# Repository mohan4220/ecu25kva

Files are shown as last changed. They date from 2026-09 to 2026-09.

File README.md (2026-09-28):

# Genset ECU

Replacement engine control unit for a 25 kVA Kirloskar diesel genset —
engine **3GK550ETA 4SR1**, application code `GK3.8703`, 26.5 kW at 1500 rpm,
12 V system. Panel controller is a **Deep Sea Electronics DSE4522 MKII AMF**.

## Start here

**[`docs/pdf/ECU-Bible.pdf`](docs/pdf/ECU-Bible.pdf)** — everything, in reading
order, in one 328-page file. Cover, handoff, field handbook, sensor reference,
circuit reference, the specification, the decisions log, all twelve research
memos, the plan. Bookmarked, so the PDF reader's outline pane is the table of
contents.

Resuming work, or moving to another machine?
**[`docs/HANDOFF.md`](docs/HANDOFF.md)** — setup, what is verified, what is
open, and the traps that already cost a session each.
**[`docs/decisions-log.md`](docs/decisions-log.md)** — every design fork put to
the owner, with the options and the reasoning.

Prefer the browser? Three of those are live HTML:
[the handbook](docs/handbook/index.html),
[the circuit reference](docs/handbook/circuits.html) and
[the sensor reference](docs/handbook/sensors.html).

## What's in here

| Path | What it is |
|---|---|
| `docs/pdf/` | Every document as PDF — one file each, plus the combined bible |
| `docs/handbook/index.html` | The handbook: machine, 94-pin interface, the circuits in narrative, how a runaway gets stopped |
| `docs/handbook/circuits.html` | Circuit reference — all 17 blocks, each with schematic, reasoning, simulated result and model limits |
| `docs/handbook/sensors.html` | Sensor reference — every sensor, what it measures, how it's read, what the data drives |
| `docs/superpowers/specs/` | The reconciled specification — the binding source of truth |
| `refs/` | The OEM wiring diagram, the DSE4522 configuration, machine photographs, and the extracted pinout |
| `docs/research/` | Twelve research memos: engine ID, GCU, connector, injector, MCU, standards, BOM, inspection brief, sensor front-ends, injector turn-off, supervisor, driver architecture |
| `sim/` | Twenty-four SPICE circuits that run and check themselves |
| `hw/` | The ten schematic-sheet generators, the symbol/footprint generators and the netlist gate |

## Rebuilding the PDFs

```bash
.venv/bin/python docs/build_pdf.py
```

Markdown documents are converted and printed; the handbook pages are printed as
they stand, from a temporary copy with the print rules injected — the source
HTML is never edited, so a PDF cannot drift from the page it came from.

Needs Chrome or Chromium on `PATH` (it is the renderer — the only engine here
that handles the handbook's inline SVG schematics and CSS custom properties),
plus `markdown` and `pypdf`:

```bash
.venv/bin/pip install markdown pypdf
```

Page rules live in [`docs/print.css`](docs/print.css).

## Running the circuit simulations

```bash
.venv/bin/python sim/run_sim.py              # every block
.venv/bin/python sim/run_sim.py injector     # blocks matching "injector"
```

Each check is a claim about the circuit, so a red line means the **design** is
wrong, not the simulator. All seventeen blocks currently pass.

The netlists are plain SPICE — they also open directly in KiCad's built-in
simulator (Tools → Simulator), LTspice, or standalone ngspice. See
[`sim/README.md`](sim/README.md).

If `.venv` is missing, rebuild it:

```bash
python3 -m venv .venv && .venv/bin/pip install PySpice numpy schemdraw markdown pypdf
```

## Where the project stands

Phase 1 is complete: nine research memos, **seventeen verified circuit blocks**
covering the whole power chain, both sensor front-end topologies, the speed
input, the injector boost rail and its reservoir, both actuator drivers and the
CAN termination — and a specification carrying the corrections that simulation
forced, including one front-end that could not have worked as originally
specified.

Simulation has now caught a design error in roughly a third of the blocks
written. The ones worth knowing about: the discrete input was impossible as a
divider rather than merely mis-valued; the battery divider would have destroyed
an ADC pin; the MCU decoupling peaked thirty times over target against the
regulator's own output inductance; and the EMI filter handed back 12 dB at the
exact frequency it most needed to hold.

**Four unknowns closed on 18 September**, from photographs of the machine and one
manufacturer's manual — and three of the four closed *against* an inference this
project had made. The engine is **3GK550ETA 4SR1**, not the model memo 01 derived.
The panel controller is a **DSE4522**, not the KG640C the OEM diagram shows. The
connector is **Bosch `1 928 405 192` / `194`, code C**. And the controller has no
speed pickup, which memo 02 got right about the wrong device.

That cost the project its safety argument. The DSE4522 takes engine speed from
**our ECU over CAN**, so its overspeed trip is not independent of the thing it
protects against. Spec §3 is rewritten and the standalone overspeed trip module
reverts from *recommended* to **mandatory**.

**U12 now stands alone as the load-bearing unknown.** Every protective action the
controller can take ends by de-energising one fuel relay; whether its contacts
remove supply from the ECU and fuel system, or merely signal a hung ECU, decides
whether any independent protection exists.
[Memo 08](docs/research/08-engine-inspection-brief.md) is the printed checklist
for that measurement.

Three things deserve reading before anything gets built. **Memo 06** on the CPCB
IV+ position — and the machine's type approval is now a specific certificate,
`ARAI/MoEF/DGTA/IGES4/KOEL-P25/2825/24`. The single-source flag on the
**MC33816** injector driver in Memo 07. And §3's closing note: **no air-intake
shutoff exists anywhere in this design**, which means nothing here can stop a
diesel running away on its own lubricating oil.

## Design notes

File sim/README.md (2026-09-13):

# Circuit simulation

Every circuit block in this ECU has a SPICE netlist here and a set of checks
that must hold. A check is a claim about the circuit — "reads logic high at a
6 V cranking dip", "never exceeds the MCU's absolute maximum" — so a failure
means the **circuit** is wrong, not that the simulator is unhappy.

This is how design errors get caught before copper. Two were caught on the
first run; both are described at the bottom of this file.

## Running

```bash
.venv/bin/python sim/run_sim.py              # every block
.venv/bin/python sim/run_sim.py battery      # blocks matching "battery"
```

Output is a table, one line per claim, green or red.

## What you need

Already present on this machine:

- **KiCad 7.0.11**, which ships `libngspice.so.0` — that shared library *is*
  the simulator, and `sim/lib/ngrun.py` drives it directly.
- **`.venv`** with numpy. Created with `python3 -m venv .venv` and
  `.venv/bin/pip install PySpice numpy`.

If `libngspice.so.0` lives somewhere else on your machine, point `NGSPICE_LIB`
at it.

## Opening these circuits in a GUI

The netlists are plain SPICE and are not tied to this harness:

- **KiCad** — Tools → Simulator, then load the `.cir` file. You already have
  this installed.
- **LTspice** — free from Analog Devices, runs under Wine. Open the `.cir`
  directly. Best waveform viewer of the three.
- **ngspice** on its own — `sudo apt install ngspice`, then
  `ngspice sim/blocks/battery_sense.cir`.

Each netlist carries its own `.control` block, so it runs and writes its data
files without any extra setup.

## Layout

```
sim/
  lib/ngrun.py     driver -- talks to libngspice over ctypes
  blocks/*.cir     one netlist per circuit block, heavily commented
  run_sim.py       the checks
```

The comments inside each `.cir` explain *why* the circuit is shaped the way it
is, not just what the components are. Read those first — they carry the
reasoning that the schematic alone cannot.

## Errors this has already caught

**Battery sense divider fed 4.7 V into a 3.3 V ADC.** The value inherited from
the earlier design documents — 75 kΩ / 10 kΩ — was sized for a 5 V ADC. The
MCU is an S32K148 with a 3.3 V analog supply, so at the top of the 40 V input
range that divider delivers 4.69 V to a pin rated 3.3 V. Corrected to
120 kΩ / 10 kΩ, which peaks at 3.07 V. The simulation keeps both in the
netlist so the difference stays visible.

**The discrete input could not be built as a divider at all.** Pins 20, 24 and
71 are active-high switched battery. Reading logic high at a 6 V cranking dip
needs a divider ratio above 0.385; staying under 3.3 V at 40 V needs it below
0.0825. Those do not overlap — *no* fixed ratio works. The fix is a different
topology: a zener sets the clamp level and the divider only biases into it, so
the logic level is flat to within 92 mV across the entire 6–40 V range instead
of tracking the battery. This one is worth understanding, because it is not
obvious from a schematic that the original was impossible rather than merely
mis-valued.

## Circuit schematics

Six schematics live in [`docs/handbook/circuits/`](../docs/handbook/circuits/), as SVG
(scalable, theme-aware) and PNG (fixed dark-on-white, for slides). They are
generated from `sim/draw_schematics.py`, which mirrors the netlists in
`sim/blocks/` -- so the picture and the thing that gets simulated cannot drift
apart. Regenerate with:

```bash
.venv/bin/python sim/draw_schematics.py
```

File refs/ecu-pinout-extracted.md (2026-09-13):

# Kirloskar ECU — pinout extracted from GP3.8703.C4.pdf

Source: Kirloskar Oil Engines troubleshooting wiring diagram, manual `08-GP3-60-001`,
retrieved from `ikonnect.kirloskar.com`. PDF dated 2026-09-04.

This file records **only what the diagram shows**. Inferences and design decisions
live elsewhere. Where the diagram is ambiguous it is marked `[?]`.

The ECU physical connector is **94-pin** (PDF page 4). The wiring diagram shows
roughly 44 of those 94 pins — the ones relevant to field troubleshooting. Power
grounds, unused pins and internal-only pins are **not** shown. A complete pinout
requires the connector part number and the OEM pin list.

## Wire colour classes (PDF page 2 legend)

| Colour | Meaning |
|---|---|
| Red | DC positive, sensor supply voltage, AC phase 1, AC single phase, **injector output high side** |
| Black | DC negative, battery ground, sensor ground, AC neutral, **injector output low side** |
| Magenta | Analog input, PWM output, low side (on/off) |
| Cyan | Digital input, frequency input, frequency output |
| Yellow | CAN H, AC phase 2, **SENT interface** |
| Green | CAN L |
| Blue | AC phase 3 |

## Power

| ECU pin | Signal | Notes |
|---|---|---|
| 21 | Battery + feed | Red. Runs to battery/starter distribution |
| 04 | `V_V_BAT_1R` | Red, via **10 A** fuse, splice S8 |
| 06 | `V_V_BAT_2R` | Red, via **10 A** fuse |
| 09 | `SYNCHRONIZATION GROUND` | Drawn red despite "ground" in the name `[?]` |

Battery-negative / power-ground pins are not shown on the diagram.

## Analog sensors

| ECU pin | Signal | Sensor | Sensor pin |
|---|---|---|---|
| 11 | Switch Battery 5V | Boost P&T combo (4-pin) | 3 |
| 41 | Analog I/P _Pressure | Boost P&T combo | 4 |
| 79 | Analog I/P _TEMP. | Boost P&T combo | 2 |
| 34 | Sensor Ground | Boost P&T combo, via splice V3 | 1 |
| 33 | Analog I/P | Coolant temperature (2-pin) | 1 |
| — | Sensor Ground | Coolant temperature — **splices into V3 → pin 34** | 2 |
| 15 | Switch Battery 5V | EGR position (part of 5-pin EGR connector) | 3 |
| 37 | Analog I/P | EGR position | 5 |
| 36 | Sensor Ground | EGR position, via splice V4 | 4 |
| 39 | Switch Battery 5V | Oil pressure (3-pin) | B |
| 80 | Analog I/P | Oil pressure | C |
| — | Sensor Ground | Oil pressure — **splices into V4 → pin 36** | A |
| 32 | Switch Battery 5V | Rail pressure (3-pin) | 3 |
| 35 | Analog I/P | Rail pressure | 2 |
| 08 | Sensor Ground | Rail pressure — **dedicated, not spliced** | 1 |

Sensor-ground grouping as wired: `34` = boost + coolant, `36` = EGR + oil,
`08` = rail pressure alone, `30` = crank alone, `44` = cam alone.

## Speed sensors

| ECU pin | Signal | Sensor | Sensor pin |
|---|---|---|---|
| 45 | Switch Battery 5V | Camshaft speed (3-pin, Hall — square-wave symbol) | 3 |
| 46 | Frequency I/P | Camshaft speed | 2 |
| 44 | Sensor Ground | Camshaft speed | 1 |
| 52 | Frequency I/P HIGH | Crankshaft speed (3-pin, VR) | 2 |
| 74 | Frequency I/P LOW | Crankshaft speed | 1 |
| 30 | Sensor Ground | Crankshaft speed | 3 |

Crank pins 1/2 are drawn as a twisted pair. Cam pins are also twisted.

## Digital inputs

| ECU pin | Signal | Colour | Notes |
|---|---|---|---|
| 43 | Digital I/P — coolant switch | Cyan | Switch element drawn at the pin |
| 23 | Digital I/P — droop switch | Cyan | |
| 01 | `G_G_B AT1` | — | Switch return / ground leg |
| 02 | `G_G_B AT2` | — | Switch return / ground leg, splice V2 |
| 20 | `AUDIO ABORT` | **Red** | Red ⇒ switched-battery, i.e. active-high |
| 24 | `OVERSIDE SWITCH` | **Red** | Traces via XC1/XC11 pin 18 to `-S7 Override SS SW` |
| 71 | `IGNITION` | Red | |

`OVERSIDE SWITCH` (pin 24) and `Override SS SW -S7` are the **same component**.
There is no separate overspeed switch.

## Outputs

| ECU pin | Signal | Colour | Notes |
|---|---|---|---|
| 88 | `PWM Output` → fuel metering unit | Black | Metering unit pin 1. Pin 2 is fed from fused battery (20 A, `8F1`) ⇒ **low-side PWM drive** |
| 59 | `EGR HIGH` | Magenta | EGR connector pin 1 |
| 81 | `EGR LOW` | Black | EGR connector pin 2. High/Low pair ⇒ bridge drive |
| 50 | `MAIN RELAY` | Black | Low-side |
| 69 | `BUZZER RELAY` | Black | Low-side |

## Injectors — bank-shared high side

| ECU pin | Signal | Goes to |
|---|---|---|
| 03 | Injector output **HIGH side** | **Cylinder 1 pin 1 AND cylinder 3 pin 1**, joined at splice V5 |
| 05 | Injector output **HIGH side** | Cylinder 2 pin 1 |
| 73 | Injector output LOW side | Cylinder 1 pin 2 |
| 07 | Injector output LOW side | Cylinder 3 pin 2 |
| 29 | Injector output LOW side | Cylinder 2 pin 2 |

Two high-side banks, three low-side selects — **5 pins, not 6**. Bank A = cyl 1+3,
bank B = cyl 2. Injector connectors are 2-pin.

## CAN — two channels

| ECU pin | Signal | Colour |
|---|---|---|
| 55 | CAN H (channel 1) | Yellow |
| 77 | CAN L (channel 1) | Green |
| 87 | CAN H (channel 2) | Yellow |
| 86 | CAN L (channel 2) | Green |

Both drawn as twisted pairs with bidirectional markers.

## Signals that are NOT on the ECU

These appear in the system but route through the XC11/XC1 36-pin harness
connectors to the panel/GCU, not to the ECU:

- **Fuel level sensor** (2-pin variable resistor) → XC pin 22, wire `1C2`
- **Water-in-fuel switch** (`WIF SW`, 3-pin) → XC pin 16/1, wire `4B`

Present in the connector appendix (PDF pages 3–4) but not traced to an ECU pin
anywhere in the diagram — needs confirmation against a different variant or a
fuller document:

- **Intake Throttle Valve** connector — **6-pin**
- **Catalyst Temperature Sensor** connector — 2-pin, **one only**
- **Fuel Pump** connector — 2-pin
- **Charging Alternator** connector — 2-pin

## Absent from the entire system

No magnetic pickup (MPU). No DEF/urea sensor. No LIN bus. No SCR. No barometric
sensor in the harness. No separate overspeed switch. Engine speed reaches the
GCU over CAN only.

## Other system components named

Genset control unit: **Kirloskar KG640C** (terminals J1–J8).
Terminal blocks `XDBK1`/`XDBK2`/`XDBK3`, relay board `-13RB1`, battery charger
`11BC1`, starter `8STR1` with solenoid `-SOL`, alternator `8ALTR1`, fuse `F1 40 A`,
MCB `F3 40A/3P 10kA`, power terminal board `XPTB1` 100/125 A 415 VAC 3-phase.

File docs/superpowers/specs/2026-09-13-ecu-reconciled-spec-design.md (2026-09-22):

# Genset ECU — Reconciled Specification

**Date:** 2026-09-13
**Status:** Phase 0 — supersedes all four prior artifacts
**Target:** Functional replacement for the `ENGINE CONTROL UNIT` block of Kirloskar
wiring diagram `08-GP3-60-001`, on a 25 kVA diesel genset with a 12 V / 75 Ah battery.

---

## 1. Why this document exists

Four artifacts precede this one:

| Artifact | Rev | Role |
|---|---|---|
| Genset ECU Design Brief | J | Spec |
| ECU Circuit Guide | H | Per-block why/how/prove |
| ECU Circuit Schematics | H | 15 topology sheets |
| PCB Design Roadmap | A | Brief → fab sequence |

They were written by reverse-engineering the Kirloskar wiring diagram from memory
of it, not from the document itself. Now that `GP3.8703.C4.pdf` is in hand, roughly
a third of their content is wrong — not stylistically, but in ways that change the
BOM, the driver topology and the pin count.

**This document is the single source of truth from here.** Where it contradicts an
artifact, this document wins. The artifacts remain useful for the reasoning behind
blocks that survived unchanged, and the Circuit Guide's "prove it" bench procedures
remain valid for those blocks.

Raw extracted evidence: [`refs/ecu-pinout-extracted.md`](../../../refs/ecu-pinout-extracted.md).

---

## 2. What changed, and why it matters

### 2.1 Injector drive is bank-shared

The diagram traces injector high-side pin `03` to **both** cylinder 1 and cylinder 3,
joined at splice V5. Pin `05` serves cylinder 2 alone. Low-side selects are individual:
`73` (cyl 1), `07` (cyl 3), `29` (cyl 2).

Five pins, two banks. The artifacts specify an independent high/low pair per cylinder —
six pins, three banks — which would put three boost stages on a board that needs two.

This is the conventional arrangement: the boost converter and high-side switch are the
expensive, thermally-significant parts, so they are shared across cylinders that never
fire simultaneously. Cylinder selection happens on the low side, which is cheap.

**Consequence:** two high-side bank switches, one shared boost rail, three low-side
current-controlled selects.

### 2.2 Fuel metering unit is low-side PWM, not an H-bridge

Metering unit pin 2 sits on fused battery (20 A, `8F1`). Pin 1 goes to ECU pin `88`
on a black wire — the low-side class per the page-2 legend. The ECU sinks current;
it does not source it, and it never reverses polarity.

The Design Brief specifies a TLE9201SG H-bridge with one leg tied off. That works
electrically but buys a reversing bridge for a solenoid that only pulls one way.

**Consequence:** one high-current low-side driver with current sense, closed-loop in
firmware. One fewer part family to source.

### 2.3 Fuel level and water-in-fuel are not ECU signals

Both route through the XC11/XC1 36-pin harness to the panel — fuel level to XC pin 22
(wire `1C2`), water-in-fuel to XC pin 16/1 (wire `4B`). Neither reaches an ECU pin
anywhere in the diagram. They belong to the GCU.

**Consequence:** two analog front-ends and two connector positions removed.

### 2.4 Discrete inputs are active-high, not active-low

`AUDIO ABORT` (20), `OVERSIDE SWITCH` (24) and `IGNITION` (71) are all **red** wires —
switched battery. The switch connects the pin *to battery*, not to ground.

The artifacts specify pull-up to 5 V with the switch closing to ground. That is the
opposite sense, and the front-end is wrong for it: these pins see battery voltage,
not 5 V, so they need a divider rated for the full 6–40 V input range plus a clamp.

The fail-safe reasoning also inverts. Circuit Guide Group D argues that normally-closed
wiring makes an open harness read as a fault. With switched-battery inputs an open wire
reads "not asserted" — indistinguishable from a switch that simply isn't pressed. That
argument does not hold here and should not be repeated in the new design. Detecting an
open wire on these inputs requires either a pull-down and a diagnostic current source,
or accepting that it is not detectable. **We accept it is not detectable** and note it
in the FMEA, because changing the sense would break harness compatibility.

Pins `01` (`G_G_B AT1`) and `02` (`G_G_B AT2`) are ECU-provided return/ground legs for
the switch circuits. The coolant switch (`43`) and droop switch (`23`) are cyan —
digital-input class — and are conventional switch-to-return inputs.

### 2.5 Both CAN channels are real

Pins `55`/`77` and `87`/`86` are both drawn as twisted pairs with bidirectional markers.
The artifacts treat CAN1 as a spare, DNP on the harness. In the OEM system both are wired.

**Consequence:** populate both transceivers and both connector positions.

### 2.6 Scope reductions confirmed

None of the following exist anywhere in this system: magnetic pickup unit, DEF/urea
sensor, LIN bus, SCR, separate overspeed switch, barometric sensor in the harness.
There is **one** catalyst temperature sensor connector (2-pin), not three EGT channels.

`OVERSIDE SWITCH` (pin 24) and `Override SS SW -S7` are one component. The Design Brief
lists them as two.

---

## 3. Safety position

> **Revised 18 Sep 2026 — second revision, and it moves in the pessimistic direction.**
> The genset controller has been photographed and identified. It is a **Deep Sea
> Electronics DSE4522 MKII AMF (India SP)**, part `4522-001-01`, serial 11021794 —
> **not the KG640C** that the OEM wiring diagram shows and that research memo 02
> analysed. This section was built on memo 02. Its central claim is now known to be
> false for the device actually fitted, and the relaxation that claim bought is
> withdrawn.

### What changed

The previous revision rested on this: *the controller senses speed from alternator
frequency, not from CAN, so its overspeed trip cannot be defeated by a hung ECU.*

That is true of the KG640C. **It is not true of the DSE4522.** From DSE's own operator
manual for the DSE4510/4520 MKII (document `057-260`, the 4522's siblings):

> "If the unit has been configured for CAN, compatible ECU's receive the start command
> via CAN and **transmit the engine speed to the DSE controller**."

and, in the engine-at-rest detection logic:

> "Engine speed is zero **as detected by the CAN ECU**"

**Engine speed reaches this controller from our ECU, over CAN.** The configured
overspeed shutdown at 1710 rpm therefore reads a number we send. An ECU that hangs
while transmitting a stale, plausible speed defeats it completely — which is precisely
the failure mode this section exists to guard against.

### What is confirmed, and what replaces it

**No magnetic pickup — now confirmed rather than inferred.** The DSE4522's full
terminal list runs 1–35 and contains no speed-pickup input of any kind: 1–2 DC supply,
3–4 outputs A (FUEL) and B (START), 5 charge fail/excite, 6–9 outputs C–F, 10 sensor
common, 11–13 analogue sensors, 14–17 digital inputs, 18–20 CAN, 21–24 generator
voltage sensing, 25–28 mains, 29–35 CTs, charge alternator and comms. Read from the
manufacturer's own terminal table, not from a diagram's silence.

**An independent path does still exist — but it is a different mechanism, and a more
conditional one.** The module measures **generator frequency directly** at terminals
21–24, straight off the alternator's three phases. It does not use CAN to do this. The
configuration sets:

| Protection | Trip | Source | Equivalent speed (4 poles) |
|---|---|---|---|
| Generator **over-frequency** shutdown | **56.0 Hz** (112 %) | Alternator terminals 21–24 — **independent of CAN** | **1680 rpm** |
| Engine **over-speed** shutdown | 1710 rpm | **CAN, from our ECU** | 1710 rpm |

On a 4-pole alternator at no slip, speed and output frequency are rigidly linked. The
over-frequency trip fires at **1680 rpm, before** the CAN-dependent overspeed trip at
1710 rpm, and it cannot be defeated by anything our ECU does or fails to do.

**Its conditions, stated plainly.** It is a *generator* protection being relied on as an
*engine* protection, and it inherits that mechanism's dependencies: the alternator must
be excited and producing measurable output, and the AVR must be working. An excitation
failure removes the protection. That is a narrower guarantee than a magnetic pickup
watching the flywheel, and it should not be described as equivalent to one.

### Where the chain terminates — U12 CLOSED 18 Sep 2026, and it closed badly

> **The measurement came back: the fuel relay cuts a signal. It does not remove power.**
>
> Reported from the machine alongside two other findings — the intake throttle and the
> pre-heat/post-heat heaters are all fed **from the battery**, not from the ECU.
>
> This is the outcome the inspection brief told the reader to flag immediately rather
> than save for a writeup, and the reasoning below was written before the answer was
> known. It stands as written; what follows is what it now means.
>
> **Both independent lines of defence are gone, for two separate reasons.**
>
> The controller has no independent speed path — it takes engine speed from this ECU
> over CAN (U13, closed 18 Sep). And its every protective action terminates in a relay
> that only signals. So a hung ECU keeps the fuel metering unit energised, and the
> device that is supposed to catch that is asking the hung ECU how fast the engine is
> turning.
>
> What survives: generator over-frequency at 56 Hz, measured from the alternator, which
> does not depend on this ECU for its *measurement* — but which acts through the same
> signalling relay. It can detect the runaway. It cannot stop it.
>
> **Confidence, stated honestly.** Brief task 1.4 exists because a normally-closed relay
> produces the same voltage reading with the opposite meaning, and it is not confirmed
> that 1.4 was performed before this result. The wording reported ("cuts signal") is a
> statement about function rather than a raw voltage, which suggests tracing rather than
> a single measurement — but that is an inference about how the work was done, not
> evidence. Adopting the unsafe reading costs nothing if it is wrong; adopting the safe
> one and being wrong costs the machine. Confirmation is still wanted, and it does not
> gate anything, because nothing below changes if it comes back the other way.

Every protective action this controller can take ends at the same place: it
de-energises **DC Output A, terminal 3, the FUEL relay** (rated 10 A for 10 s, 5 A
continuous — a relay coil driver, consistent with it operating the 70 A `-13RB1`
contactor in the OEM diagram).

So the independent over-frequency path is only as good as what that relay's contacts
carry. If they remove supply from the ECU and the fuel metering unit, the path works. If
they merely signal a hung ECU, **the path terminates in the failure it was meant to
catch**, and there is no independent protection at all.

That is U12, unchanged in substance and now the single load-bearing measurement in this
section.

### The position for this design

1. The ECU implements overspeed shutdown in firmware as a **primary** function, with the
   crank sensor as its input, at the highest scheduling priority. First line, and it is
   ours.
2. The controller's **generator over-frequency shutdown at 56 Hz**, measured directly
   from the alternator, is the **second line**. It is independent of this ECU but
   conditional on alternator excitation. We must not weaken it: the ECU must not latch
   the fuel metering unit on in a way that survives its supply being removed, and must
   fail safe when the ignition input at pin 71 drops.
3. A standalone MPU-driven overspeed trip module is **mandatory again**, not
   recommended. The relaxation in the previous revision was bought entirely by the claim
   that the controller had an independent *speed* path; that claim is false for the
   fitted device. What remains is a generator-frequency protection with an excitation
   dependency, terminating in a relay whose function is unverified. That is not enough
   to carry a 25 kVA set on its own. Two candidates are costed in memo 02
   (GAC SSW675, Murphy HD9063) — that costing survives even though the memo's device
   analysis does not.
4. ~~**The gate: U12 must be closed by measurement before any build takes injection
   authority.**~~ **Closed 18 Sep 2026, in the failing direction.** The gate was written
   to admit the possibility that U12 came back clean. It did not. The relay signals, so
   line 2 detects a runaway without being able to act on it, and item 3's "mandatory" is
   no longer a precaution against an unverified relay — it is the only shutdown path on
   this machine that does not run through the ECU being protected against.

5. **The trip module must break the fuel metering unit's supply directly.** This follows
   from U12 and is now a requirement, not a preference. A trip module that signals the
   same GCU relay chain inherits exactly the defect U12 just exposed. Its contacts have
   to sit in series with the metering unit's own battery feed — the one through fuse
   `8F1` — so that tripping removes fuel authority regardless of what the ECU, the
   controller, or the GCU relay board is doing. Both costed candidates in memo 02 are
   contact-output devices and can be wired this way; the costing survives, the wiring
   assumption behind it does not.

The owners may of course revisit item 3 with evidence. What they should not do is
inherit the previous revision's conclusion, because the fact it was built on turned out
to describe a controller that is not on this machine.

### What this ECU must do about the trip module

Item 5 puts the trip module's contacts in series with the fuel metering unit's battery
feed. That interface is the module's, not ours — but it constrains this design in three
ways, and none of them has been designed against yet.

**We must not be able to defeat it.** The trip module removes the metering unit's
supply. Our low-side driver on pin 88 sinks current from that supply, so when the module
trips, our output has nothing to switch. That is the property that makes the arrangement
work, and it must survive the detail: no path from any ECU output may re-energise the
metering unit around an open trip contact. Any such path would be a wiring error that
silently restores the failure mode the module exists to remove.

**We should sense its state, and treat it as an input rather than a surprise.** A trip
that removes fuel while the ECU is still commanding injection produces a fault the ECU
should recognise and report over CAN, rather than reading it as a fuelling anomaly and
compensating. The cheapest form is one discrete input sensing whether the module's
contacts are closed. That is a new connector position and a new front-end, and it does
not exist in the OEM harness — a deliberate addition, listed under §7.

**We must fail safe into it, not against it.** The module acts on overspeed sensed by
its own magnetic pickup. The ECU's own overspeed shutdown (item 1) acts on the crank
sensor. These are independent measurements of the same quantity, and they will disagree
near the threshold. The ECU must not treat its own reading as authoritative to the point
of trying to keep running through a trip.

**Not yet decided:** whether the module's pickup shares the flywheel target with our
crank sensor or gets its own. Sharing is cheaper and physically simpler; separate
targets preserve the independence that is the entire point of fitting the module. This
is a mounting question for whoever fits it, and it should be answered before the module
is ordered rather than after.

### What this section still does not address

A diesel that begins burning its own lubricating oil — through a failed turbocharger
seal or crankcase fumes drawn into the intake — has a fuel supply that **none of the
three lines above can interrupt**. Every one of them cuts diesel or electrical power.
The standard countermeasure is a mechanical or pneumatic **air-intake shutoff valve**,
and no such device appears anywhere in this design, this register, or §9's out-of-scope
list. It was never considered rather than considered and rejected.

This is recorded here, unresolved, because it is a decision for the machine's owners:
the part is mechanical, not electronic, and fitting it is not within this PCB's scope.
It should not be allowed to stay invisible.

---

## 4. ECU pin map

Confirmed pins from the wiring diagram. **44 of 94.** See §8 for the remaining 50.

### Power

| Pin | Signal | Front-end |
|---|---|---|
| 21 | Battery + feed | Main input: EMI filter → fuse → TVS → reverse-battery FET |
| 04 | `V_V_BAT_1R` (10 A fused) | **120 k / 10 k** divider → ADC; feeds high-current loads `[?]` |
| 06 | `V_V_BAT_2R` (10 A fused) | **120 k / 10 k** divider → ADC; feeds high-current loads `[?]` |
| 09 | `SYNCHRONIZATION GROUND` | Function unresolved — see §8 |

The battery-sense divider is **120 k / 10 k, not the 75 k / 10 k** inherited from
the earlier artifacts. That value was sized for a 5 V ADC and delivers 4.69 V at
a 40 V input — above the S32K148's 3.3 V analog supply. The corrected divider
peaks at 3.07 V and still resolves 573 ADC counts at the 6 V cranking dip.
Verified in [`sim/blocks/battery_sense.cir`](../../../sim/blocks/battery_sense.cir).

### Ratiometric analog — 10 k / 16 k divider, 22 nF shunt, 3.3 V clamp, rail measured and corrected in firmware

**Revised 14 Sep 2026.** This section previously specified *1 kΩ series, 100 nF
shunt, ADC ref tracks `5V_SENSOR`*, which contradicted the simulated front-end and
cannot be built on this MCU. Both halves were wrong, and for the same reason the
75 k / 10 k battery divider was wrong — they were written for a 5 V part:

- **`VREFH` cannot track `5V_SENSOR`.** The S32K148's ADC reference may not exceed
  its 3.3 V analog supply. A reference at 5 V is not an option on any 3.3 V device.
- **1 kΩ in series scales nothing.** With no division, a sensor at 4.5 V arrives at
  a 3.3 V pin. The series resistor is a fault-current limiter, not an attenuator.

So the signal must be divided, and the question becomes how to keep the
*ratiometric* property after dividing it.

**Decision: divide, then measure the rail and correct in firmware.**
`5V_SENSOR` gets its own ADC channel. Every ratiometric reading is computed as a
fraction of the measured rail rather than of an assumed 5.000 V, which is what the
sensor's output actually represents. Cost: one ADC channel, zero analog parts. The
channel budget has room — see the sensor reference.

*Rejected alternative:* dividing `5V_SENSOR` into `VREFH` by the same 16/26 ratio.
It fits numerically (5 V × 16/26 = 3.08 V, inside the 3.3 V limit) and gives true
ratiometric conversion with no firmware arithmetic. It is rejected because `VREFH`
is shared by every channel on that ADC, so it would silently make **battery sense
and the NTC channels ratiometric to the sensor rail as well** — both of which need
an absolute reference. It would also need a buffer, since a resistive divider is
too noisy and too high-impedance to drive a reference input.

**Single-ended or differential is decided by the ground, not by the channel.**
Where the sensor's return is shared, the other sensor's current develops an offset
across the harness resistance that a single-ended input reads as signal:
[`sim/blocks/sensor_differential.cir`](../../../sim/blocks/sensor_differential.cir)
measures 12 mV of bias at 1 Ω of return resistance against 0.13 mV differential.
Research memo 09 found both Deep Sea Electronics and SEDEMAC treat this as a
first-class problem. So:

- **Shared ground (pins 34, 36) → differential front-end.**
- **Dedicated ground (pin 08) → single-ended is sufficient**, because there is no
  other sensor's current in that return. This mirrors the OEM's own ranking: they
  gave rail pressure a dedicated return precisely so it would not need one.

| Pin | Signal | Group ground | Front-end |
|---|---|---|---|
| 11 / 41 | Boost: 5 V excitation / pressure signal | 34 | Differential |
| 79 | Boost: temperature signal — **topology unresolved, see §8** | 34 | Differential |
| 34 | Sensor ground — boost + coolant | — | — |
| 33 | Coolant temperature (NTC, pull-up divider) | 34 (spliced) | Differential |
| 15 / 37 | EGR position: 5 V / wiper | 36 | Differential |
| 36 | Sensor ground — EGR + oil pressure | — | — |
| 39 / 80 | Oil pressure: 5 V / signal | 36 (spliced) | Differential |
| 32 / 35 | Rail pressure: 5 V / signal | 08 | Single-ended |
| 08 | Sensor ground — rail pressure, dedicated | — | — |
| — | `5V_SENSOR` rail monitor | — | Divider → ADC, for the correction above |

Sensor-ground grouping mirrors the OEM harness exactly: `34` boost+coolant,
`36` EGR+oil, `08` rail alone, `30` crank alone, `44` cam alone. Rail pressure gets
a dedicated return because it is the most accuracy-critical analog channel on the engine.

### Speed

| Pin | Signal | Front-end |
|---|---|---|
| 52 / 74 | Crank VR: Frequency I/P High / Low | Differential adaptive-threshold conditioner → timer capture |
| 30 | Crank sensor ground | Shield terminates here, ECU end only |
| 45 / 46 | Cam Hall: 5 V / Frequency I/P | **This row was wrong — see the correction below** |
| 44 | Cam sensor ground | — |

### Discrete inputs

| Pin | Signal | Sense | Front-end |
|---|---|---|---|
| 43 | Coolant switch | Switch-to-return | Pull-up + RC debounce |
| 23 | Droop switch | Switch-to-return | Pull-up + RC debounce |
| 01 / 02 | `G_G_B AT1` / `AT2` | — | Switch return legs — but see note below, these may be power grounds |
| 20 | Audio abort | **Active-high** | 47 k / 68 k bias + 3.0 V zener clamp + 220 nF |
| 24 | Override SS | **Active-high** | same |
| 71 | Ignition | **Active-high** | same |

**The active-high front-end is not a divider, and cannot be.** Reading logic
high at a 6 V cranking dip needs a divider ratio above 2.31/6 = 0.385; staying
under 3.3 V at 40 V needs it below 3.3/40 = 0.0825. Those constraints do not
overlap, so no fixed ratio works at both ends. The zener sets the clamp level
and the divider only biases into it, which makes the logic level flat to within
92 mV across the whole range instead of tracking the battery. Verified in
[`sim/blocks/discrete_input.cir`](../../../sim/blocks/discrete_input.cir).

**Pins 01/02 need checking.** Memo 03 infers from the connector drawing that
pins 1, 2, 5 and 6 are large power contacts. Pins 05 and 06 fit that — injector
high side and a battery rail. Switch return legs would not. The likelier reading
is that `G_G_B` denotes battery ground and these are the ECU's main power
grounds, which would also explain why no power-ground pin appears anywhere in
the extraction. Queued as a continuity measurement.

### Outputs

| Pin | Signal | Driver |
|---|---|---|
| 03 | Injector high side — bank A (cyl 1 + 3) | Boosted high-side switch |
| 05 | Injector high side — bank B (cyl 2) | Boosted high-side switch |
| 73 / 07 / 29 | Injector low side — cyl 1 / 3 / 2 | Current-controlled low-side, peak-and-hold |
| 88 | Fuel metering unit PWM | High-current low-side + current sense |
| 59 / 81 | EGR High / EGR Low | H-bridge + position feedback on pin 37 |
| 50 | Main relay | Low-side FET + flyback |
| 69 | Buzzer relay | Low-side FET + flyback |

#### Cam front-end (pin 46) — this row was wrong, CORRECTED 19 Sep 2026

The outputs table said "pull-up to `5V_SENSOR` → timer capture" for the cam frequency
input. A Hall sensor pulled up to the 5 V sensor rail swings to 5 V, and the S32K148 is a
3.3 V part. Taken literally, that drives an MCU pin above its absolute maximum.

It survived because **nothing simulated it.** There is a `vr_conditioner` block for the
crank sensor and no cam equivalent, so the mechanism that catches this class of error
never looked. Found by the pin-map work, on the way to something else.

This is the second front-end here specified in a way that would have destroyed a pin. The
first was a divider on the battery sense — caught by `battery_sense.cir`, precisely
because a block existed.

**Now built:** `sim/blocks/cam_frontend.cir` divides the 5 V swing into the 3.3 V domain
and verifies it across the rail's own range — 3.072 V nominal, 3.147 V at 5.25 V high
line, 2.769 V at the 4.5 V fault floor `sensor_rail.cir` established, where it still
reads a valid logic high. All clear the 3.6 V absolute maximum. It also checks a 40 V
harness short, which clamps the pad to 3.308 V with fault current held to 3.7 mA.

#### Nothing on this board protects the buck against a NEGATIVE input — GAP, found 19 Sep 2026

`sim/blocks/negative_pulses.cir` simulated ISO 7637-2's negative transients for the first
time, which became possible only once the TVS stopped being modelled as a single diode.

**The LM5164's VIN pin is rated −0.3 V to 100 V.** The negative limit is not a mirror of
the positive one, and nothing in this design was ever sized against it. Read from TI's own
absolute-maximum table.

With the reverse-battery FET assumed still conducting — the honest assumption, since no
turn-off delay is sourced anywhere and pulse 3a is only 0.1 ms wide:

| Pulse | Buck VIN | Past the −0.3 V rating by |
|---|---|---|
| 1 (−150 V / 10 Ω / 2 ms) | **−40.7 V** | 135× |
| 3a (−220 V / 50 Ω / 0.1 ms) | **−27.8 V** | 93× |

The bidirectional TVS clamps correctly. It clamps to its own breakdown, and −38 V is a
perfectly good clamp that is still two orders of magnitude outside what the buck
tolerates. **This is a missing component, not a mis-sized one** — the chain has no series
element or shunt diode addressing a negative excursion.

**And the reverse-battery stage cannot be assumed to cover it.** If its controller opens
fast enough the buck is isolated almost perfectly; if not, the FET conducts and the buck
sees the full clamped negative voltage. `reverse_battery.cir` models instant turn-off and
its own RESULT NOTE warns it "will always look perfect in reverse". **No controller part
is chosen and no turn-off delay is sourced**, so both bookends are simulated and neither
is claimed. That delay is now a load-bearing number, and this decision should be taken
with the controller selection rather than separately.

#### Every driver gate is held off by hardware, not by firmware — REQUIRED 18 Sep 2026

Research memo 11 establishes the hazard with the MCU's own datasheet numbers rather
than by argument. Two facts combine badly:

- **S32K148 GPIOs are high-impedance out of reset**, until firmware configures them.
  High-impedance on a gate driver is not "off" — it is undefined, and the gate can be
  brought up by leakage or by capacitive coupling from a switching node.
- **There is a band where nothing internal resets the part.** Low Voltage Reset always
  forces a reset at 2.50–2.7 V, but Low Voltage Detect at 2.8–3.0 V only does so if
  firmware has set `LVDRE`. Below the datasheet's own 2.97 V correctness guarantee and
  above LVR, the core may execute wrong instructions **with its outputs still driven**.

The pin that makes this concrete is **88**. The fuel metering unit is fed from battery
through fuse `8F1` and switched low-side by this ECU (§2.2). A gate floating high during
reset energises the metering unit with no firmware in control of it — and, since U12,
with nothing downstream able to remove its power either.

**Therefore, as a binding requirement on every driver gate in the table above:**

1. A **gate–source pulldown** at each gate node, sized by the FET actually chosen rather
   than fixed here:

   > `Rpd < Vgs(th) / (Crss · dV/dt)`

   **The dV/dt in that formula is the weakest number in this requirement, and this
   document previously overstated its standing.** It read "2.8 V/µs from
   `injector_turnoff.cir`", which is a citation that file explicitly refuses: its own
   comments say reporting a dV/dt from that model "would be exactly the kind of
   promotion-to-sourced the project's own discipline rules out." The figure is memo 10's
   **inferred** estimate — 100 V in ~36 µs — and `supervisor.cir` imports it as an
   assumed input waveform, labelled INFERRED there too. Every file closer to the number
   than this one hedges it; only the spec stated it flatly, beside genuinely simulated
   figures, where it read as one of them.

   **It is also an average, not a peak, and the error runs in the unsafe direction.**
   100 V over 36 µs is the mean slope of the whole turn-off. Miller coupling happens
   during the plateau, where a real FET slews far faster. The requirement's sensitivity
   to that, at Crss = 500 pF:

   | dV/dt | gate through 470 Ω | Rpd actually needed |
   |---|---|---|
   | 2.8 V/µs (the assumed average) | 0.66 V — ok | < 714 Ω |
   | 10 V/µs | 2.35 V — over threshold | < 200 Ω |
   | 28 V/µs | 6.58 V — over threshold | < 71 Ω |

   At 200 Ω the gate driver would need an output impedance near 10 Ω; at 71 Ω a passive
   pulldown cannot be driven at all. **So the 470 Ω answer survives only at the assumed
   average**, and a modest factor on the real slew rate removes the passive-pulldown
   topology entirely rather than merely resizing it.

   **A second assumption pulls the other way.** The 470 Ω also assumes Vgs(th) = 1.0 V,
   the conservative end of a 1.0–2.5 V class range with no part chosen. Read at 2.5 V the
   same sweep gives **1000 Ω and a ≤52.6 Ω driver**. So:

   | Assumption | Direction | Effect on 470 Ω |
   |---|---|---|
   | Vgs(th) 1.0 V vs 2.5 V | permissive if wrong | 470 Ω is **pessimistic** — costs drive current, not safety |
   | dV/dt 2.8 V/µs (an average, not a plateau slew) | **unsafe if wrong** | 470 Ω is **optimistic** — a real slew of 10 V/µs demands 200 Ω |

   The slew-rate assumption is the larger lever and the dangerous direction. **Treat
   470 Ω as a demonstration, not a value to build to:** what it actually shows is that a
   passive pulldown alone lives in a narrow window bounded by two numbers nobody has
   measured. That conclusion holds whichever way either assumption lands, and it is the
   argument for the active clamp — which `sim/blocks/supervisor.cir` has already
   validated, and which research memo 12 recommends building discretely regardless of
   the driver-architecture decision.

   At a 1.0 V threshold that is **under 1.79 kΩ for Crss = 200 pF, 714 Ω at 500 pF,
   357 Ω at 1000 pF**. `sim/blocks/supervisor.cir` claim 6 sweeps this directly and
   lands on **470 Ω** at Crss = 500 pF — twenty times smaller than the figure this
   requirement first carried.

   **That value constrains the gate driver, and the two cannot be specified apart.**
   At 10 kΩ the pulldown was a perturbation on the driver. At 470 Ω it is the bottom
   half of a divider with the driver's own output impedance:

   > `Vgs = Vdrv · Rpd/(Rpd + Rdrv)` — holding 9.5 V across 470 Ω needs **Rdrv ≤ 24.7 Ω**

   It also costs **21.3 mA per gate and 1.28 W across all six**, continuously, whenever
   the FETs conduct. Stating the pulldown as a single number hid both the coupling and
   the power.

   **This reopens a topology question memo 11 closed on the bad arithmetic.** The memo
   considered an active clamp and dismissed it. A passive pulldown strong enough to
   reject Miller coupling at 500 pF is strong enough to fight its own driver and burn
   over a watt doing it — which is the trade an active clamp exists to avoid, and which
   an integrated driver in the MC33814 class handles internally. That decision is now
   coupled to the driver-architecture decision below and should be taken with it.

   **This requirement said "10 kΩ" when first written on 18 Sep 2026, and that was
   wrong.** Memo 11 §4 computed the Miller-coupled current correctly at 140–560 µA and
   then mis-multiplied, reporting 5.6 mV across 10 kΩ where the answer is 5.6 V.
   `sim/blocks/supervisor.cir` was built to check that paragraph and fails it at 50 pF,
   the low end of the memo's own range. The memo now carries the correction inline. The
   error is recorded rather than quietly patched because it survived a review, a spec
   commit, and was caught only by simulating the claim.
2. A **windowed supervisor** monitoring `3V3_MCU`, tripping at **~3.05–3.10 V**, above
   LVD's 3.0 V maximum, so the trip does not depend on whether firmware ever configured
   `LVDRE`. Its watchdog window must close well inside one cylinder interval (26.67 ms
   at 1500 rpm).
3. The supervisor's reset, inverted, driving a **kill transistor at each protected
   gate**, so the safe state is enforced independently of GPIO configuration. A plain
   timeout watchdog is defeated by a stuck loop that still kicks it; the window is what
   closes that.

This is the ECU's own fail-safe and it is **separate from the standalone trip module**
of §3. The trip module removes fuel authority from outside the board; this keeps the
board's own outputs defined while it still has power. Neither substitutes for the other,
and since U12 neither is optional.

**Open, and blocking the detail rather than the requirement:** the physical `PTxx`
assignment for pins 88, 73/07/29 and 03/05 is a phase-2 task (§5), so the per-pin reset
pull defaults cannot yet be looked up. The requirement above does not depend on them —
it exists precisely so that the answer does not matter — but the analysis cannot be
finished until the pin map is fixed.

#### Input protection — RESOLVED 20 Sep 2026, and it moved three other parts

Two decisions, taken together because they are coupled.

**1. TVS: SMBJ33CA → SMCJ43CA.** The standoff had to clear the 40 V clamped load dump so
the part stops conducting during a normal event — that is what `load_dump`'s failure was
actually saying. 43 V is the smallest standard bin above 40 V, and smallest matters
because clamping voltage rises with the bin and everything downstream sees it.

The package changed too, and that was forced by simulation rather than chosen. At the
600 W SMBJ size, pulse 2a clamped at **88.6 V** against the buck's 100 V absolute
maximum — 11 % margin, too thin to design to. The 1500 W SMCJ part has half the dynamic
resistance at the same standoff and clamps at **73.3 V**, restoring 1.37× margin.

Result: `load_dump` now draws **0.000 A and absorbs 0.000 J** — the TVS simply stays off
through the dump, which was the predicted fix and is now the simulated one.

**2. A negative clamp diode at the buck input.** The TVS holds the node at its own
−47.8 V breakdown, which is a correct clamp and still two orders of magnitude outside the
buck's **−0.3 V** rating. A 60 V / 20 A-class Schottky, anode to ground and cathode to
VIN, conducts long before the TVS does:

| Pulse | Buck VIN before | After |
|---|---|---|
| 1 | −40.7 V | **−0.53 V** |
| 3a | −27.8 V | **−0.39 V** |

**The residual is honest and still fails its check.** 0.53 V is 1.76× the −0.3 V rating,
not inside it. No silicon diode reaches 0.3 V at the ~15 A this fault delivers. Closing
the last 0.23 V needs series impedance — the EMI filter's ferrite sits upstream and is
not modelled here — or a judgement that a sub-microsecond 0.2 V excursion past a DC
absolute maximum is acceptable. **That is a question for the part's manufacturer, and it
is now a bounded one rather than a missing component.**

**What this moved elsewhere:** the reverse-battery P-FET sits downstream of the clamp, so
it now needs **100 V class, not 60 V** — its third revision, each time because the clamp
moved. `transient_clamp.cir` now carries an explicit check stating the downstream
requirement, so the next move does not have to be noticed by a human reading three files.

#### The EGR driver must decode IN1/IN2 internally — REQUIRED 19 Sep 2026

`sim/blocks/egr_hbridge.cir` argued that no IN1/IN2 combination could short a leg,
because each input line drives a *diagonal* pair. A review falsified it against the
block's own wiring: IN1 commands leg-A-high and leg-B-low, IN2 commands leg-B-high and
leg-A-low, so asserting **both** turns all four switches on and shorts **both legs**
rail-to-ground at once. Simulated at **270 A**, matching the hand figure of two legs of
2 × 50 mΩ across 13.5 V.

The reasoning failed by checking each input line alone and never asking what the two do
together.

**Nothing on this board currently prevents that state.** The gate pulldowns hold both
lines low at reset, which is correct and not the issue — the exposure is any fault or
firmware error that drives both high.

**The requirement:** the EGR driver must decode IN1/IN2 so that the 11 state means brake
or coast and never shoot-through. Integrated H-bridge drivers do this internally, and
that now counts as a reason to prefer one here — note that memo 12's driver decision
covered the *injectors* and explicitly did not address EGR. If the driver is discrete,
the interlock has to be built, and **a per-leg dead time is not sufficient on its own**:
this fault is a logic state, not a timing overlap.

**RESOLVED 20 Sep 2026.** The same bridge driven through a decoded DIR/PWM interface,
with **both** inputs asserted — the combination that shorts the naive arrangement — draws
**4.35 A**, which is the motor's own stall current, not a short. 270 A against 4.35 A.
The fault state does not exist under decode; it is not merely made less likely.

`egr_hbridge.cir` now simulates both, and the naive wiring is kept as **evidence of why
the requirement exists** rather than as a live failure — the same treatment
`battery_sense.cir` gives the divider it rejected.

**What to draw:** an integrated H-bridge with a decoded DIR/PWM (or equivalent
non-shoot-through) input interface, current limiting, and headroom over the actuator's
stall. `egr_hbridge.cir` puts stall at **2.6–6.4 A** across a plausible armature
resistance range, with no actuator chosen — so specify a part with comfortable margin
over 6.4 A and confirm against the actuator once U8-class information arrives. Candidate
parts are not named here: none has been checked against a retrieved datasheet, and this
project's rule is that an unread figure does not become a design number.

#### Driver architecture — DECIDED 19 Sep 2026, research memo 12

**Discrete power MOSFETs with a gate-driver IC for the injector banks, keeping the
100 V boost rail. An integrated smart low-side switch for the metering unit. An active
kill-clamp at every gate of both, built discretely.**

The decision was forced by one confirmed number. The two integrated injector-driver ICs
that fit this design's channel count and current class both cap their boost rail **below
the 100 V already chosen**: MC33816's `VBOOST` absolute maximum is **72 V** (NXP
datasheet Rev 10.0), and L9781's tank voltage is reported at 80 V — snippet only, its
datasheet having failed retrieval across two independent sourcing passes.

Adopting either would force the boost rail down and re-derive three already-passing
blocks. Memo 12 re-did that arithmetic: at 72 V the peak-phase ramp stretches from
38 µs to **53 µs**, which still fits a pilot injection but consumes half of it.

**And neither part removes the work.** Both are pre-drivers, not integrated power
stages — external MOSFETs, external boost inductor and diode, and external sense shunt
are required either way. MC33816 additionally brings its own microcode toolchain.
MC33814 is the wrong class outright: 1.3 A continuous against an 18 A requirement, and
no boost stage at all.

**On the coupled clamp question, the integrated route relocates the problem rather than
removing it** — and does so in a form worth copying. MC33816's high-side pre-driver is
*actively forced low* on reset, falling back to a weak 500 kΩ–2 MΩ resistor only once
its bootstrap capacitor is exhausted. That is the same two-tier structure
`supervisor.cir` already validated, on a different bias rail, and with no datasheet
statement about how fast that bootstrap decays under brownout — where `supervisor.cir`
claim 4 gives a timed guarantee. **So build the active clamp discretely regardless.**
This was never a question the IC-versus-discrete decision could have answered
differently.

**What would change this:** a retrieved L9781 datasheet showing a tank voltage at or
above 100 V, or a decision to accept a ≤72 V rail on other grounds.

**Two sourcing items escalated and unresolved:** MC33816AE carries a distributor
last-time-buy date of 06/08/2027, and the L9781 datasheet has now failed retrieval five
times across two sessions. Both need a human with distributor or FAE access rather than
another automated fetch.

### CAN

| Pin | Signal |
|---|---|
| 55 / 77 | CAN channel 1 — H / L |
| 87 / 86 | CAN channel 2 — H / L |

---

## 5. MCU selection

**Recommendation: NXP S32K148.** This resolves the contradiction in the artifacts —
Design Brief §03 specifies MPC5744P while its own §02 block diagram and §06 sensor table
still say S32K148 and FTM.

The argument for MPC5744P was angle-synchronous injection timing needing the eTPU2.

> **Corrected 2026-09-13** after research memo 05 challenged the original reasoning and
> was right to. This section first argued that constant 1500 rpm operation relaxes the
> timing problem because a crank degree is 111 µs and a 60-tooth wheel gives an edge
> every 667 µs. That checks the wrong variable. Crank-edge *capture* rate was never the
> binding constraint in either case — at 6000 rpm a 60-tooth wheel produces an edge
> every **83 µs**, which is about **6,700 CPU cycles** at 80 MHz against an NVIC latency
> of roughly 12. The comparison was never close, so constant speed cannot be what makes
> it comfortable. The reasoning below replaces it.
>
> **Re-corrected 18 Sep 2026.** This box said "an edge every 28 µs, which is over 2000
> CPU cycles". 28 µs is the **one-degree-of-crank** period at 6000 rpm (10,000 µs ÷ 360),
> not a tooth-edge period — a unit conflation, off by a factor of six, sitting inside a
> box that was itself written to fix an earlier reasoning error. A 60-tooth wheel at
> 6000 rpm gives 166.7 µs per tooth and 83.3 µs per edge counting both polarities.
>
> The conclusion is unaffected and in fact strengthened: the correct figure gives *more*
> margin, not less. It is corrected because a wrong number that happens to support the
> right answer is still a wrong number, and this one would have been inherited by anyone
> reasoning forward from it.

**What the eTPU2 actually buys.** It is a co-processor that autonomously schedules and
re-schedules many angle-domain output-compare events across a wide and *rapidly changing*
speed range, without consuming the main CPU's interrupt budget and without the core's
scheduling jitter — cache effects, higher-priority ISRs, RTOS latency — reaching the
injection timing chain. That matters when rpm sweeps 800–6000 with tight transient
response and pilot/main/post multi-pulse strategies all landing within microseconds of a
moving target angle.

**Why we don't need it.** This set governs to a fixed 1500 rpm, and the pin map in §4
shows a single main injection pulse per cylinder per cycle — one bank high-side plus one
low-side select, with no multi-pulse rate shaping in scope. The constraint that does bind
is **injector pulse-width resolution**, which sets fuel-quantity metering accuracy and is
independent of crank speed. FlexTimer output-compare runs off the bus clock: one tick is
12.5 ns at 80 MHz, 8.9 ns at 112 MHz HSRUN. Against a single-pulse metering requirement
on the order of 1–4 µs, that is roughly 100–450× headroom.

The S32K148 also carries 2× Programmable Delay Blocks, which trigger ADC conversions or
timer events at a defined delay from a capture event in hardware. That recovers part of
what the eTPU2 offers — jitter isolation on the timing chain — without the eTPU2.

**Caveat carried forward:** the 1–4 µs resolution figure is a general diesel-injector
engineering figure, not this injector's datasheet. Revisit if U5 closes with a part
demanding materially finer control, or if multi-pulse injection ever enters scope.

What the S32K148 buys in exchange:

- Free S32 Design Studio; GCC ARM toolchain; cheap CMSIS-DAP/J-Link probes instead of
  a Power Architecture Nexus pod
- Stock KiCad symbol availability, or trivially built from NXP's own EVB files
- Real availability in small quantities in India
- 3× FlexCAN (we need 2); dual 12-bit ADC against a demand of ~14 channels — 8 sensor
  inputs, 2 battery-rail senses, and 4 current-sense returns from the injector, metering
  and EGR drivers; FlexTimer instances well beyond the ~10 timing channels required
  (crank capture, cam capture, 3 injector low-side, 2 injector high-side, metering PWM,
  2 EGR bridge PWM)
- No eTPU2 microcode, which is a specialist skill and a hiring risk on a small team

**Confirmed in Phase 1** — see [`docs/research/05-mcu-selection.md`](../../research/05-mcu-selection.md).
Orderable part **FS32K148HAT0MLQT**, 144-pin LQFP, 80 MHz RUN / 112 MHz HSRUN grade,
−40…+125 °C. In stock at DigiKey India at roughly ₹1,900–2,000/unit. The S32K146
fallback was checked and is in worse supply shape (backordered, 12–52 week spread), so
it is not needed.

Two items deferred to Phase 2: confirming how many ADC channels the 144-pin package
actually breaks out (needs the reference manual's pin-mux table, not the datasheet), and
pad-by-pad verification of the SOT486-2 package drawing before the footprint is locked.

**Pin map done, 19 Sep 2026 — see [`docs/pinmap.md`](../../pinmap.md).** The first of
the two deferred items above is closed: the Reference Manual's own embedded
`S32K148_IO_Signal_Description_Input_Multiplexing.xlsx` (not the datasheet) gives 128
GPIO-capable pins on the 144-pin package, of which this design commits 37, including all
94-way connector signals with a confirmed identity (spec §4). It also settles §4's
own deferred fail-safe detail: all six gate pins (88, 73/07/29, 03/05) are confirmed
high-impedance with no pull at reset, exactly the condition §4's hardware kill-clamp was
already designed against. One new finding surfaced in the process: pin 46's cam
front-end, as specified above, would put a 5 V swing on a 3.3 V MCU pin — flagged there,
not fixed here. Package pad-pitch verification remains open.

---

## 6. Power architecture

Unchanged from the artifacts in topology; the reasoning there is sound.

| Stage | Function |
|---|---|
| EMI input filter | Common-mode choke, CISPR 25 conducted margin |
| Reverse-battery | Ideal-diode controller + P-FET, < 0.3 V drop |
| Transient clamp | Bidirectional TVS, ISO 7637-2 pulses incl. load dump 5b |
| Buck pre-regulator | 6–40 V → 5 V, wide-input synchronous |
| `5V_SENSOR` | PTC-protected per sensor group, isolated from MCU rails |
| `3V3_MCU` | LDO off 5 V |
| Supervisor | Windowed watchdog + brown-out reset |

Input range 6–40 V: 6 V covers the cranking dip on a 12 V system, 40 V bounds the
clamped load-dump transient.

**Injector boost rail** is new relative to the power chain as drawn: a separate boost
stage generating the injector opening voltage, with its own reservoir bank sized for
the pulsed draw of two banks. Target voltage is set by the injector part — see §8.

---

## 7. Deliberate deviations from the OEM design

Recorded so they are choices, not drift:

1. ~~**Connector split.** The OEM uses one 94-pin connector. We use functionally-split
   sealed connectors. This simplifies harness build and field diagnosis, at the cost
   of needing an adapter harness to mate with an unmodified Kirloskar loom. That
   adapter is a deliverable, not an afterthought.~~

   **REVERSED 22 September 2026, by the owner.** The ECU carries the **OEM connector
   described in the field evidence** — Bosch `1 928 405 192` / `1 928 405 194`,
   **code C**, 94-way, EDC17 family (`refs/field-evidence-2026-09-18.md` §2b) — and
   plugs straight into the unmodified Kirloskar loom. **No adapter harness.** This is
   no longer a deviation from the OEM design.

   Consequences, all already reflected elsewhere: the board-side land pattern is now
   load-bearing (field brief task 5.3, and a Bosch distributor quoting both numbers,
   since neither returns a catalogue hit); **code C** keying must match exactly; and
   the harness-side questions — which cavity is the power ground (task 5.1), and a
   pin and wire for the new `TRIP_LOOP` (task 5.2) — are answered in the OEM loom
   itself rather than designed into an adapter.
2. **Onboard barometric sensor.** Not present in the OEM harness. Added on-PCB behind
   a vented port; costs nothing in harness terms and improves fuelling correction.
3. **Independent overspeed path.** Added, per §3. The OEM does not have one.

---

## 8. Unknowns register

Nothing in this list may be guessed into copper. Each needs an answer before the
sheet that depends on it is drawn.

Status updated at phase 1 exit, 14 Sep 2026. Three states, and the middle one
carries weight: **Open** means no answer yet; **Answered** means phase-1 research
produced an answer that is good enough to design against but is *inferred*, not
confirmed, and still carries the upgrade path in its memo; **Closed** means
confirmed outright. Nothing here is Closed yet — every confirmation on this list
needs the machine.

| # | Unknown | Status | Blocks | How to close |
|---|---|---|---|---|
| U1 | ECU connector identity | **CLOSED 18 Sep 2026** — **Bosch**, part numbers `1 928 405 192` and `1 928 405 194`, **`code C`** mechanical keying. 94 cavities: power pins 1–8 in their own chamber, then rows 9–28, 29–50, 51–72, 73–94 | — | Closed by markings on the part. Note: an adapter housing **must be code C** or it will not mate |
| U2 | Boost air-temp (pin 79): NTC or ratiometric? | Open | Sheet 3b front-end | One resistance reading, sensor cold — brief task 1.3, closes it outright. **Mitigation: a front-end that works either way** |
| U3 | Controller MPU input — does it exist? | **CLOSED 18 Sep 2026 — No.** The fitted controller is a **DSE4522 MKII**; DSE manual `057-260`'s terminal table runs 1–35 with no speed-pickup terminal | §3 | Closed from the manufacturer's own terminal list |
| U4 | Controller J1939 expectations | **Largely answered** — CAN source addresses **234** (engine) / **44** (instrumentation); J1939-75 instrumentation on, alarms off; the controller takes **oil pressure, coolant temperature, coolant level and ENGINE SPEED** from our ECU over CAN; `ECU Data Fail → Shutdown` | Firmware, CAN sheet | Remaining: the exact PGN set. Log the live bus, or read DSE publication 057-004 |
| U5 | Injector part number and drive profile | **Partly answered** — memo 04 gives a family envelope (65–115 V, 12–24 A peak, 8–13 A hold, 40–100 A/ms) sufficient to design the driver | Boost rail *target* voltage, not the driver sheet itself | Photograph the injector body for a Bosch `0445 1xx xxx` or Kirloskar `F6.xxx.xx.x.pr`. **Separately: the calibration data is a different problem — see §9 and memo 04** |
| U6 | Pin 09 `SYNCHRONIZATION GROUND` function | Open | Power/ground plan | OEM pin list; drawn red despite the name |
| U7 | Pins 04/06 — sense only, or load feeds? | Open | Power sheet current rating | Measure on the live engine, or OEM pin list |
| U8 | 6-pin intake throttle — on the ECU at all? | **Partially answered 18 Sep 2026** — reported **battery-fed**, so the ECU does not supply it | Whether a throttle *driver* is in scope. Supply and control are separate questions and only supply is answered | Still needs brief task 3.11: follow the cable and see whether it terminates at the 94-way connector. A battery-fed actuator can still be ECU-commanded |
| U9 | Catalyst temp sensor — connected where? | Open | Whether an EGT front-end is in scope | Trace on the engine |
| U10 | `SENT` in the colour legend — which signal? | Open | Possible digital sensor front-end | Inspect harness; SENT is SAE J2716 |
| U11 | Engine identity | **CLOSED 18 Sep 2026** — rating plate reads **3GK550ETA 4SR1**, app code **GK3.8703**, 26.5 kW at 1500 rpm, type approval `ARAI/MoEF/DGTA/IGES4/KOEL-P25/2825/24`. Memo 01's inferred `3R550ETA 4G1` was **wrong**; the original "GK550" was right | — | Closed by plate |
| U13 | Which controller is fitted | **CLOSED 18 Sep 2026** — **DSE4522 MKII AMF (India SP)**, part `4522-001-01`, serial 11021794. Photographed front and rear. **Not a KG640C.** Memo 02 superseded; spec §3 rewritten | — | Closed by photograph |
| U14 | Pre-heat / post-heat: driven by the controller or by the ECU? | **Partially answered 18 Sep 2026** — reported **battery-fed** | Whether a heater *output* is in scope. As with U8, supply is not control | Who switches that battery feed is still open. The DSE4522 config enables both at 50 °C, so the controller is the likely switch — photograph the heater relay and trace its coil |
| U15 | What does `CRS-878` denote in the controller's engine profile? | **NEW 18 Sep 2026** | Possibly bears on U5 — "CRS" plausibly identifies the common-rail system | Ask KOEL, or find DSE's engine-profile list |
| U16 | **Is the battery-charging alternator's rectifier suppressed (avalanche/clamping), or unsuppressed?** | **NEW 18 Sep 2026** | **The input-protection topology.** Suppressed ⇒ ISO 7637-2 pulse 5b, ~40 V clamped, and the fix is a TVS standoff above the dump level — a part number. Unsuppressed ⇒ pulse 5a at 65–87 V unclamped, tens of joules that nothing downstream can ride out, and a different circuit | The alternator's rectifier part number (look for a suppression/avalanche bin), or a scope on the battery terminal during a live disconnect under load. The scope test needs the set running — a supervised activity, not a solo checklist item |
| U12 | **Does the 70 A ignition relay `-13RB1` remove power from the ECU and fuel metering unit, or only signal the ECU?** | **CLOSED 18 Sep 2026 — it only signals.** Reported from the machine. The relay does not remove power; a hung ECU keeps the fuel metering unit energised | **§3's safety gate, resolved against us.** The trip module is mandatory, and §3 item 5 now requires its contacts to break the metering unit's own battery feed rather than signal the same relay chain | Closed. Task 1.4's normally-closed check is still wanted as confirmation, but nothing depends on it — the unsafe reading is already adopted |

~~**U12 now stands alone as the load-bearing unknown.**~~ **U12 closed 18 Sep 2026, and
the answer was the bad one.** U13 cost this project its safety argument: the fitted
DSE4522 takes engine speed from our ECU over CAN, so the controller's overspeed trip is
not independent of the thing it is meant to protect against. What independence remained
was the generator over-frequency shutdown at 56 Hz — and every protective action the
controller can take terminates in the same fuel relay on terminal 3.

**That relay signals. It does not remove power.** So the second line of defence can
detect a runaway and cannot stop one. The two findings compound: the controller either
cannot see the fault (overspeed, read from our CAN) or cannot act on it (over-frequency,
acting through a signalling relay).

Nothing on this machine currently interrupts fuelling without the cooperation of the ECU
being protected against. The trip module in §3 item 3 is what closes that, and §3 item 5
now specifies where its contacts have to sit — in series with the metering unit's own
battery feed, not in the GCU relay chain that just failed this test.

Worth stating plainly, because it is the pattern of this whole phase: **four of the five
unknowns closed by field evidence closed against what this project had reasoned.** U11
(engine identity), U13 (which controller), U1 (connector — this one closed *for* us),
and now U12. Desk inference has a measured track record here, and it is poor.

U1, U3, U11 and U13 all closed on 18 September from photographs and one manufacturer's
manual. Three of the four closed *against* an inference this project had made, which is
the honest measure of how much desk research was carrying.

U3 and U11 were the other two on that list and are now answered, both by inference
from primary documents rather than by confirmation. Neither answer is fragile — but
both are the kind of finding that a single photograph at the machine would settle
permanently, which is why they stay on the register rather than leaving it.

U5 has moved off the critical list for a reason worth stating plainly: memo 04's
family envelope means the **injector driver can be designed now, without the part
number**. What the part number buys is a boost-rail target instead of a range. The
thing that genuinely gates running this engine is not on this register at all — it
is the injector calibration data, recorded in §9 and memo 04.

---

## 9. Out of scope

- Injection calibration: timing maps, quantity maps, rail pressure setpoint schedules.
  The hardware will be capable; the maps are a dyno programme, not a PCB deliverable.
- Emissions certification. **But read this before planning deployment** — research memo
  06 found, in primary sources, that the regulatory position is worse than "we simply
  won't certify it." CPCB's RECD System & Procedure states that ECU characteristics
  governing injection timing, air-mass metering and emission-reduction strategy must not
  be altered even under CPCB's own sanctioned retrofit scheme, and excludes changes
  limited to engine control from that scheme entirely. General Condition 3 of GSR 804(E)
  states that no person shall use a genset lacking a valid Type Approval and CoP
  certificate. No approval pathway for a third-party ECU replacement was found.

  This does not block the engineering: designing the board, building it, and bench-testing
  it against simulated signals are unaffected. It bears on **putting it into service on a
  genset that is in use**, and it compounds the calibration risk in memo 04 — this engine
  meets its limits partly through calibration, so a replacement ECU can move it out of
  compliance without any hardware changing at all.

  This is the project owners' decision to take to qualified counsel or to CPCB/ARAI
  directly. It is recorded here because it is material and was not previously examined,
  not to make the decision for them.
- The panel controller. We talk to the **DSE4522 MKII AMF**; we do not replace it. (Earlier
  revisions of this line said KG640C, which is what the OEM wiring diagram shows and not what
  is fitted — see §3.)
- Panel wiring, ATS, alternator metering.

---

## 10. Phase sequence

| Phase | Output | Status |
|---|---|---|
| 0 | This document | Done |
| 1 | Research memos: engine ID, controller, MCU confirmation, injector and connector sourcing | **Done** — nine memos |
| **1.5** | **Block-level simulation: topology and component values verified before capture** | **In progress — 17 blocks, all passing** |
| 2 | KiCad hierarchical schematic capture | Not started |
| 3 | 4-layer PCB layout, DRC, fab outputs | Not started |
| 4 | Firmware skeleton: HAL, J1939, crank sequencing, fault manager | Not started |

**Phase 1.5 was added on 18 Sep 2026 to name work that was already happening.** The
simulated blocks are neither research memos nor schematic capture, and leaving them
unnamed meant the roadmap did not describe the most productive activity on the project —
the one that caught a divider that would have destroyed an ADC pin, a discrete input that
was impossible as specified, and a decoupling network thirty times over its impedance
target. It also gives the two gaps the circuit review found — load dump, and injector
turn-off energy — a phase to belong to instead of floating as review findings.

Phase 2's blocked sheets are now fewer: **U1 is closed** (Bosch `1 928 405 192` / `194`,
code C), so the connector and adapter-harness sheets are unblocked. U2 blocks one sensor
front-end, U8 blocks whether a throttle driver exists at all, and U5 sets the boost rail's
target voltage but not the driver itself. Power, CAN, MCU support, speed inputs, the
relay outputs and the analog front-ends are all fully specified above.

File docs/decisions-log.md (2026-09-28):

# Design decisions put to the owner

Every decision here was a fork the evidence could not settle on its own:
either it changed the architecture, or it traded cost against reliability.
Each entry gives the question as it was asked, the options offered, what
was chosen, and why the question existed at all.

Dates are 2026. The standing rule from 22 September — **safety and
reliability before cost, size and convenience** — is what several of
these answers turn on.

---

## 1. The harness connector

**Asked:** the specification (§7, deviation 1) called for the OEM 94-way
connector to be replaced by functionally-split sealed connectors plus an
adapter harness. The physical part had since been identified from
photographs of the machine. Keep the deviation, or put the OEM connector
on the board?

**Chosen: the OEM Bosch 94-way on the board, no adapter.** Spec deviation
1 is recorded as reversed.

**Consequence:** the board-side land pattern is now load-bearing and has
to come from a Bosch distributor. Neither part number returns a public
catalogue hit.

---

## 2. Four part-selection findings, approved together

These four were presented as recommendations and approved with one "ok"
on 22 September. Each one came out of choosing a part and discovering the
drawn circuit could not accept it.

### 2a. Where the injector and EGR current comes from — POWER-PATH

**The problem:** every high-current load (injector hold ≈10 A, EGR up to
6.4 A stall, relay coils) draws through connector pin 21, a 20 A fuse,
the EMI filter and a reverse-battery FET. The reverse-battery block sized
that FET for **5 A**, and the EMI filter block never stated a DC current
at all. A 22 µH inductor that does not saturate at 15–20 A is a large
part. Meanwhile pins 04 and 06 are separate battery feeds, fused 10 A
each in the loom, that this board uses only to measure voltage.

**Options:** move the injector and EGR supply onto pins 04/06 with their
own protection, leaving pin 21 for the electronics; or keep everything on
pin 21 and resize the fuse, filter and reverse FET for the full load,
with one contact carrying it.

**Chosen: move the high-current loads to pins 04/06.**
**Status: not yet implemented.**

### 2b. Boost converter stability while cranking — BOOST-SLOPE

**The problem:** the injector boost controller (TPS40210-Q1) adds a fixed
internal slope-compensation ramp. Its Equation 9 caps the current-sense
resistor at `VDD·L·fSW / (60·(VOUT + VD − VIN))`, and 80% of that is the
recommended value. The drawn 82 mΩ passes at 13.5 V (ceiling 99.7 mΩ) and
**fails at the 6 V cranking corner** (ceiling 44.9 mΩ, so 1.83× over):
the converter goes subharmonic exactly when the engine is being started.
Worse, a 330 µH inductor that saturates above the 2.2 A current limit is
not a part that exists in surface mount — the search found 330 µH parts
rated 0.2–0.4 A — and the buildable direction, a smaller inductor, lowers
the ceiling further (100 µH allows 30 mΩ).

**Options:** feed the controller's supply pin from the output side, which
is TI's own remedy and steepens the ramp, and use 100 µH; or accept
subharmonic operation while cranking.

**Chosen: feed VDD from the clamped output side, 100 µH.**
**Status: not yet implemented.** The finding is pinned as a check.

### 2c. Sensor-supply protection — SENSOR-PTC

**The problem:** the requirement asked for a resettable fuse of "R25 =
3.0 Ω nominal, −30% spread". Real PTCs are not specified that way: Bourns
MF-USMF020 gives a **range, 0.40–5.00 Ω**, and at its 0.40 Ω minimum it
contributes 14% of the series resistance the fault-current ceiling
assumed. Its hold current also halves from 0.20 A at 23 °C to 0.10 A at
85 °C, against a ≥200 mA requirement.

**Chosen (first pass): a fixed series resistor sets the fault ceiling and
the fuse only trips.** This was later superseded — see decision 4.

### 2d. The 3.0 V and 3.3 V input clamps — LOWV-CLAMP

**The problem:** fifteen zeners clamp the analog, speed and discrete
inputs. They were specified at 5 mA but sit at tens of microamps, where a
sub-5 V zener's knee is soft. The datasheet allows **10 µA of leakage at
only 1 V**. On a discrete input, 10 µA through the ~28 kΩ source is
0.28 V against a logic-high margin of 0.36–0.41 V while cranking; on an
analog input it is a signal-dependent error on the ADC. The simulation's
idealised sharp-knee zener hid all of it.

**Chosen: replace them with a low-leakage clamp to the 3.3 V rail
(BAV199).**
**Status: done for the analog and cam inputs; the discrete inputs needed
a different answer — see decision 3.**

---

## 3. The discrete switch inputs

**Why it came back:** BAV199 works where a clamp only conducts on a
fault. The five switch inputs clamp **continuously**, because a 6–40 V
input cannot be divided into logic range otherwise: reading a logic high
at 6 V needs a divider ratio above 0.385, and staying under 3.3 V at 40 V
needs one below 0.0825. Those do not overlap. Three candidate clamps were
checked and all three fail:

| Candidate | Why it fails |
|---|---|
| 3.0 V zener (BZX84-C3V0-Q) | soft knee at µA; the leakage that started this |
| Rail clamp (BAV199-Q to 3V3) | parks the pad at 3.9 V continuously — beyond the pin's rating, as an operating point rather than a fault |
| Shunt reference (LM4040-Q1 3.0 V) | draws ~35 µA of bias below breakdown (TI SNOS633N, Fig. 5-4); the cranking-dip input can supply only 20 µA, so the node sags to ~2.6 V with no guaranteed bound, and it fails outright on the pull-up channels |

**Options offered:** an NPN buffer per input; a stronger drive plus the
LM4040, with special cases for the two contact-to-ground channels; or a
dedicated automotive switch-detection IC on SPI.

**Chosen: the NPN buffer.** 10 kΩ into the base, 4.7 kΩ and 4.7 µF to
ground, a BAV199-Q diode holding the base against reverse battery, and
the transistor's collector as the MCU pin with a 10 kΩ pull-up to 3.3 V.
The pad now only ever sees 0–3.3 V, and nothing on it has to conduct
continuously.

**What the safety rule changed inside this decision:** the input resistor
was first drawn at 100 kΩ, which draws 0.11 mA through a closed contact
at 12 V. Non-gold switch and relay contacts at that current oxidise into
an intermittent open — a field failure, not a bench one. 10 kΩ gives
1.1 mA. Everything is checked at the worst corner rather than typical:
hFE 30 (datasheet minimum 60, halved for −40 °C) still pulls the pad to
0.03 V from a 6 V input, and a typical part at 125 °C stays off below a
1.3 V input.

**Cost:** the logic is inverted — pad low means input active — which is
recorded in the pin map, and the failure modes (transistor open reads
inactive, collector-emitter short reads active) are handed to the
firmware plausibility spec, because one polarity cannot make every
channel fail safe.

**Status: done.**

---

## 4. The 5 V sensor supply

**Why it came back:** the fix approved in 2c does not survive the real
source impedance. The sensor rail block modelled the 5 V supply as ideal
behind 0.1 Ω, but it comes from a **1 A buck**. So:

- a shorted sensor harness hits the buck's current limit long before any
  fuse trips; 5V_MAIN collapses, 3V3_MCU follows it, and the supervisor
  shuts the engine down. One chafed wire stops the machine.
- a sensor supply wire shorted to **battery** back-feeds 24 V into
  5V_MAIN through the fuse. No series resistor or PTC prevents that.

**Options offered:**

| Option | What it buys | What it costs |
|---|---|---|
| Tracker per group + overvoltage cut-off | each group survives a short to ground *and* to battery; other groups and the MCU are unaffected | about 8 more parts |
| Series resistor + PTC (as approved in 2c) | cheapest | a harness short browns out the MCU; a battery short back-feeds the rail |
| Trackers fed directly, with a lower main TVS | fewer parts | rewrites the whole board's transient design, and needs the alternator question (U16) answered first |

**Chosen: a tracking regulator per sensor group (TPS7B4253-Q1, whose
output survives −1 to +45 V and limits at 301–520 mA, tracking 5V_MAIN to
±4 mV) behind a 100 V-class overvoltage cut-off.**

**Why the cut-off is needed:** the tracker's input pin is rated 45 V and
this board's battery rail reaches 73.3 V for 50 µs on ISO 7637-2 pulse
2a. The cheap alternatives were worked through and discarded: a series
resistor with a TVS must clamp below 45 V, so it would conduct through
the entire 400 ms load dump (about 7 J), and any series resistance breaks
the 0.52 V of dropout headroom at a 6 V cranking input; an emitter or
source follower loses its own Vbe/Vgs at that same corner. A cut-off
instead disconnects for the 50 µs pulse, while a 47 µF capacitor holds
the sensors up (0.16 V of droop), and stays connected through the 40 V
dump.

**Status: not yet implemented.**

---

## Where these came from

Nothing here was found by reading the schematic. Each one surfaced when a
part number was chosen and its datasheet was checked against what the
drawing assumed — which is the same shape as every earlier finding in
this project: a document and an executable check disagreeing, with
nothing comparing them until someone did.

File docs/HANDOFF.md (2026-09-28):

# Handoff — state of the project, 28 September 2026

Written for the next session (human or Claude) picking this up on
another machine. It says what exists, what is verified, what is open and
what to do next. `docs/status.md` remains the long-form record; this is
the short one.

---

## 1. Standing rules — these override defaults

1. **Safety and reliability come before cost, size and convenience.**
   Check at worst-case corners (datasheet min/max, −40 °C and +125 °C,
   105 °C board ambient, reverse battery, ISO 7637-2 pulse 2a), never at
   typical. Prefer a topology that removes a failure mechanism over one
   that manages it. State failure modes and which direction is safe.
2. **No AI attribution in commits.** No `Co-Authored-By`, no "Generated
   with" line. (Commits `1332322`..`7a189fe` carry such trailers from
   before the rule; they are left alone deliberately — do not rewrite
   that history.)
3. **Deliverables are files in this repository.** No externally hosted
   pages.
4. **Verify with the project venv and `set -o pipefail`.** Never a bare
   `python3`, and never `| tail` in a chain that gates a commit — a
   piped tail once let a 22/24 suite into a commit claiming 24/24.
5. **Nothing is claimed without a check that runs.** A caveat in prose
   gets believed; a corner that is written as an enforced check is the
   one that gets caught. Every finding in this project was found this
   way.

---

## 2. Setting up on a new machine

```bash
git clone https://github.com/mohan4220/ecu25kva.git
cd ecu25kva
python3 -m venv .venv                 # .venv is git-ignored
.venv/bin/pip install numpy markdown matplotlib pypdf
```

System packages (not pip):

| Need | Why | Notes |
|---|---|---|
| `kicad` 7.x, with `kicad-cli` | netlist export, SVG/PDF plots | schematics are generated, never hand-edited |
| KiCad stock symbol + footprint libraries | `/usr/share/kicad/{symbols,footprints}` | `hw/gen_footprints.py` derives from them |
| `libngspice.so.0` | the simulator, driven by ctypes | override the path with `NGSPICE_LIB=` if it lives elsewhere |
| `inkscape`, `imagemagick` | only for eyeballing rendered sheets | optional |

Verify the whole project in one go:

```bash
set -o pipefail
.venv/bin/python sim/run_sim.py | tail -3        # expect 24/24 blocks pass
.venv/bin/python hw/check_netlist.py | tail -6   # expect "schematic connectivity OK", 2 open items
.venv/bin/python hw/assign_passives.py           # expect 202 packaged, 0 unresolved
.venv/bin/python docs/build_pdf.py | tail -1     # rebuilds docs/pdf/ECU-Bible.pdf
```

**The schematics are generated.** Edit `hw/gen_sheet_*.py`, then
`.venv/bin/python hw/gen_sheet_<name>.py --force`. Without `--force` the
generator refuses to overwrite a non-empty file. After adding or
re-valuing any R or C, re-run `assign_passives.py` and then regenerate
the sheets again so the footprints land.

---

## 3. Where things stand

**Phase 2 (schematic capture) is complete and checked.** Ten
hierarchical sheets, root wired, project netlist verified. Phase 3
(part selection) is most of the way through; phase 4 (PCB) has not
started, and no firmware exists.

| Gate | State |
|---|---|
| Simulation blocks | **24 of 24 pass** |
| Netlist connectivity | **passes**, with 2 named open items |
| Footprints | **300 of 319** components |
| Chip R and C packaged | **202 of 202** |

**Verified part numbers** are in `docs/bom_requirements.md` under
"Chosen parts" — every one against a datasheet that was actually
retrieved and read. That now covers the MCU, regulators, supervisor,
gate drivers, current-sense and difference amplifiers, comparator, the
boost controller, all sixteen power FETs, the small-signal FETs, 27
diodes, the gate-rail transistors, the buck inductor, and the packaging
of every chip resistor and capacitor.

**Design decisions taken with the owner** are in
`docs/decisions-log.md` — the four approved findings, the discrete-input
redesign and the sensor-supply redesign, with the options and reasoning
for each.

---

## 4. What is open, in the order I would do it

### 4.1 Three approved redesigns, not yet built

1. **POWER-PATH** — move the injector and EGR supply onto connector
   pins 04/06 (10 A fused each in the loom) with their own protection,
   leaving pin 21 feeding the electronics through the EMI filter and
   reverse FET. Today every high-current load runs through a path whose
   reverse FET was sized for 5 A and whose filter never stated a DC
   current. Blocks: L101, L102, F101. See `docs/bom_requirements.md`
   § POWER-PATH.
2. **SENSOR-PTC → trackers** — one TPS7B4253-Q1 per sensor group, ADJ
   tracking 5V_MAIN, behind a 100 V-class overvoltage cut-off (an
   LTC4368-class controller was the candidate; **its datasheet was not
   retrieved yet — do that first**) with a 47 µF hold-up capacitor. The
   cut-off exists because the tracker's IN pin is rated 45 V and the
   rail reaches 73.3 V for 50 µs. Replaces F201–F203 and the whole
   SENSOR-PTC requirement. `sensor_rail.cir` needs rewriting with it,
   including the fault-containment check (one group shorted, the other
   two and the MCU unaffected).
3. **BOOST-SLOPE** — feed the TPS40210's VDD from the clamped output
   side to steepen its internal ramp, and drop L401 to 100 µH (Würth
   7447709101, Isat 3.1 A typ, AEC-Q200). Re-check TI Equation 9 at the
   cranking corner after the change; the current design is 1.83× over
   its ceiling there. The check that pins the finding is in
   `run_sim.py` under `boost_converter`.

### 4.2 Parts still unchosen

- **C401** — 47 µF, 150 V class injector reservoir (electrolytic; needs
  a ripple-current and ESR-at-−40 °C check, since it delivers the
  injection pulse).
- **C313** — 150 µF polymer bulk, specified as an **ESR band** of
  20–50 mΩ across −40/+125 °C, not a ceiling. See `PDN-BULK`.
- **The trip-loop clamp** — the LOWV-CLAMP residual. It is the one input
  that still needs a continuous clamp, because its healthy band *is* the
  clamp level. It is also blocked on a connector pin.

### 4.3 Blocked on the machine or a supplier

- **The power ground.** GND reaches the connector only through
  sensor-ground pins 8/30/44. The 18 A injector return has no pin. The
  netlist gate now counts this as an open item rather than passing
  silently. Field brief tasks 1.1 and 5.1 settle it — pins 01/02
  (`G_G_B AT1/AT2`) are the hypothesis.
- **`TRIP_LOOP` has no connector pin** — it is not on the OEM diagram
  and needs one of the 50 unconfirmed pins.
- **The Bosch 94-way land pattern** — needs a distributor drawing for
  1 928 405 192 / 194, code C. The board carries the OEM connector
  (spec §7 deviation 1 reversed), so this is the board's own header.
- **U16, the alternator rectifier** — still decides which ISO 7637-2
  pulse applies, and would change the transient design if answered.
- **MC33816AE last-time-buy 06/08/2027**, and the **L9781 datasheet**
  (five failed retrievals) — both need a distributor or FAE, not
  another search.

### 4.4 The 19 components still without a footprint

| Parts | Why |
|---|---|
| D408–D414 (VS-16EDH02HM3 ×7), L201, J1001 | chosen, but no KiCad 7 land pattern — must be drawn |
| L101, L102, F101 | blocked on POWER-PATH |
| L401 | blocked on BOOST-SLOPE |
| F201–F203 | blocked on the sensor-supply redesign |
| C313, C401 | not yet chosen |
| D806 | the trip-loop clamp, the LOWV-CLAMP residual |

`hw/gen_footprints.py` is where a drawn land pattern goes. It derives
footprints from stock ones by renumbering pads, and already carries two
(a TO-277A and a SOT-23 zener whose stock pad numbering would otherwise
have reversed the part).

### 4.5 Then

Firmware skeleton (phase 4) and PCB layout (phase 5). Layout should not
start before POWER-PATH is settled, since it changes which copper
carries 18 A.

---

## 5. Traps worth knowing before editing

These each cost a debugging session already:

- **A wire endpoint landing mid-span does not connect** in KiCad 7, even
  with a junction in the file. The page plots correctly and the netlist
  says "unconnected". Use `schlib.Rail`, which splits every segment at
  its taps.
- **A label's justification is read in its own rotated frame.** At 180°,
  "left" puts the text back across its own wire. Both label types are
  fixed in `schlib`; keep it that way.
- **Pin numbers are not pad numbers.** A SOT-23 FET symbol (G-S-D) on a
  DPAK footprint puts the source on the tab. Power FETs use the G-D-S
  symbols; BJTs in SOT-23 are B-E-C; BZX84 zeners and TO-277A diodes
  need the renumbered footprints from `gen_footprints.py`.
- **Auto-generated net names move.** `Net-(R407-Pad2)` changes the
  moment a part is added ahead of it, and `assign_passives.py` keys
  voltages on net names — so give any node whose voltage matters a real
  label.
- **`--force`**, or the generator keeps the existing sheet.
- **Simulation models hide things.** An idealised zener hid both the
  leakage that started LOWV-CLAMP and an 84 mV loading error that a
  passing check had pinned as the expected value. When a model's part
  gets chosen, re-fit the model to the datasheet.

---

## 6. Repository map

| Path | What it is |
|---|---|
| `hw/gen_sheet_*.py` | the ten sheet generators — the schematic source of truth |
| `hw/schlib.py` | drawing primitives, pin geometry, the chosen-parts table |
| `hw/assign_passives.py` | packages every chip R and C from the voltage across it |
| `hw/gen_symbols.py`, `hw/gen_footprints.py` | project symbols and renumbered footprints |
| `hw/check_netlist.py` | the connectivity gate: shadowed nets, decoupling, rails, open items |
| `sim/blocks/*.cir` | 24 self-checking SPICE blocks |
| `sim/run_sim.py` | runs them and asserts every claim as arithmetic |
| `docs/bom_requirements.md` | requirements, chosen parts, and the open design items |
| `docs/status.md` | the long-form running record |
| `docs/decisions-log.md` | decisions put to the owner, with options and reasoning |
| `docs/pinmap.md` | pin assignments, including the inverted discrete inputs |
| `docs/research/` | twelve research memos |
| `refs/` | OEM wiring diagram, machine photographs, extracted pinout, field evidence |

`README.md` is stale in its counts (it said 163 pages,
17 blocks and nine memos; it is now 328 pages, 24 blocks and twelve
memos, and it has been corrected). Worth a pass.

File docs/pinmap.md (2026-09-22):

# MCU Pin Assignment — S32K148 to the 94-way Bosch Connector

**Date:** 2026-09-19
**Status:** Phase 2, first artifact. Unblocks the per-pin fail-safe detail spec §4 deferred
and the two Phase-2 items memo 05 §7 left open (how many ADC/FTM channels the 144-pin
package actually breaks out; per-pin reset defaults for the six gate pins).

---

## 0. Preamble — package, sources, method

**Package assumed: 144-pin LQFP, orderable part `FS32K148HAT0MLQT`.** This is the package
already selected in spec §5 and confirmed in `docs/research/05-mcu-selection.md` — chosen
as headroom against the 50 still-unresolved OEM connector pins (U1's register), not
because the *confirmed* 44-pin budget needs it. This document does not revisit that
choice; it uses the `S32K148_144lqfp` column of NXP's own pin table throughout.

**Documents retrieved this session, fresh, not from memory:**

- **NXP, *S32K1xx Data Sheet*, Rev. 15, 5 March 2026** — `nxp.com/docs/en/data-sheet/S32K1xx.pdf`,
  the same revision `docs/research/05-mcu-selection.md` cites. Used for the LVR/LVD
  electrical thresholds (§3 below) and to confirm the datasheet itself defers the pinout
  table to the Reference Manual (§10.1, "For package pinouts and signal descriptions,
  refer to the Reference Manual" — this is a direct quote, not a paraphrase, and it is
  why memo 05 could not close its own two Phase-2 items from the datasheet alone).
- **NXP, *S32K1xx Series Reference Manual*, Rev. 13, 04/2020** — retrieved from
  `community.nxp.com` (the same mirror memo 05 found but did not open). **This PDF has
  eleven Excel workbooks embedded as file attachments**, including
  `S32K148_IO_Signal_Description_Input_Multiplexing.xlsx` — the actual chip-specific
  pin-mux table the Reference Manual's own Chapter 4 says exists but does not inline
  ("IO Signal Description Input Multiplexing sheet(s) attached to the Reference Manual").
  Extracted with `pdfdetach` and read directly (893 rows, `IO Signal Table` tab). **This
  is the primary source for every `PTxx` ↔ peripheral ↔ package-pin-number claim in this
  document, all tagged CONFIRMED below**, and it is the single fact this whole exercise
  turned on: the manual's *narrative* text was retrievable by search all along, but the
  actual per-pin table was not, because it lives in an attachment nobody had opened.
- Sensor front-end topology and signal counts: `docs/superpowers/specs/2026-09-13-ecu-reconciled-spec-design.md`
  §4/§5, `refs/ecu-pinout-extracted.md`, `sim/blocks/*.cir` (read, not modified),
  `docs/research/05-mcu-selection.md`, `docs/research/12-driver-architecture.md`.

**One revision gap, disclosed rather than smoothed over.** The Reference Manual pulled
this session is Rev. 13 (04/2020); the datasheet memo 05 cites is Rev. 15 (2026). No
higher-revision Reference Manual was located or checked. Pin multiplexing is a silicon
mask property, not a document-editing one, and no revision-history entry in either
document (datasheet's own changelog was searched) mentions a pinout or signal-mux change
for the S32K148 specifically — but this is **INFERRED**, not independently confirmed
against a Rev.-15-class Reference Manual, because none was found. If a newer RM surfaces
before schematic capture, diff its `S32K148_IO_Signal_Description_Input_Multiplexing.xlsx`
against the one this document used before trusting a pin unchanged.

**Package pin budget, checked rather than assumed:** the embedded table lists 157 `PTxx`
port pins across the whole S32K1xx family tree; **128 of them are bonded out on the
144-pin LQFP package** (the rest exist only on the 176-pin part or the BGA). This document
commits **39** of those 128 to a signal (37 as first written, plus the two watchdog pins
§1.8 adds). That leaves 89 GPIO-capable pins unused — enough
margin that the 50 still-unknown OEM connector pins (spec §8) will not run the package out
of pins once their function is known, which was an open question memo 05 flagged and this
answers: **the 144-pin package was the right headroom call.**

**Reserved and excluded from this map, deliberately:** `PTA4`/`PTC4`/`PTC5` (JTAG
TMS/TCK/TDI) and `PTA5` (dedicated `RESET_b`) are the only four pins on the whole part
with a reset default other than high-impedance-disabled (Reference Manual §4.4,
Table 4‑3 — see §2 below). None of the 94 connector signals are placed on them. `PTB6`/
`PTB7` (`XTAL`/`EXTAL`) are not used by any signal here either, but whether this design
needs an external crystal at all is not decided anywhere in the repo — flagged in §5.

---

## 1. The mapping table

Columns: **ECU pin** (Bosch 94-way, per spec §4 / `refs/ecu-pinout-extracted.md`),
**Signal**, **Front-end** (from spec §4 / `sim/blocks/`, not re-derived here),
**`PTxx`**, **Peripheral**, **Reset pull** (CONFIRMED from the embedded IO Signal Table —
every non-JTAG/RESET pin reads `PE=0, PS=0`, i.e. **disabled, high-impedance, no
pull**, matching RM §4.4 Table 4-3's blanket "Others: Disabled, High impedance" row), and
a **Note** giving the one-line reason for anything not a free choice.

A pin bearing "—" in the `PTxx` column is not an MCU signal at all — it is a power,
ground, or excitation-supply net that terminates at the power tree or the sensor-ground
plane, not at a GPIO. Those are listed so that every one of spec §4's 44 confirmed
connector pins is accounted for, not silently dropped.

### 1.1 Power

| ECU pin | Signal | Front-end | `PTxx` | Peripheral | Reset pull | Note |
|---|---|---|---|---|---|---|
| 21 | Battery + | Reverse-battery FET → buck | — | — | — | Power input net, not an MCU signal |
| 04 | `V_BAT_1R` sense | 120k/10k divider (spec §4) | `PTA0` | ADC0_SE0 | Hi-Z, no pull | Free choice; paired with pin 06 on the *other* ADC instance (below) so both battery rails sample simultaneously |
| 06 | `V_BAT_2R` sense | 120k/10k divider | `PTA2` | ADC1_SE0 | Hi-Z, no pull | Paired with 04 for simultaneity — a real S32K148 property (two independent SAR ADCs), not decorative |
| 09 | `SYNCHRONIZATION GROUND` | — | — | — | — | **U6 open.** Function unconfirmed; likely a ground per its own name despite being drawn red. No MCU pin assigned — assigning one would be guessing a signal that may not exist |

### 1.2 Analog sensors

| ECU pin | Signal | Front-end | `PTxx` | Peripheral | Reset pull | Note |
|---|---|---|---|---|---|---|
| 11 | Boost sensor 5V excitation | `5V_SENSOR` distribution | — | — | — | Power net, not an MCU input |
| 41 | Boost pressure | Differential (shared gnd 34) | `PTA1` | ADC0_SE1 | Hi-Z, no pull | |
| 79 | Boost temperature | Differential or NTC — **U2 open, topology TBD** | `PTA3` | ADC1_SE1 | Hi-Z, no pull | One ADC pin serves either candidate front-end in `ntc_frontend.cir`; the pin choice does not depend on U2's answer |
| 34 | Sensor ground (boost+coolant) | Instrumentation-amp reference | — | — | — | Analog ground-plane net, not a GPIO |
| 33 | Coolant temperature | Differential (shared gnd 34) | `PTA6` | ADC0_SE2 | Hi-Z, no pull | |
| 15 | EGR 5V excitation | `5V_SENSOR` distribution | — | — | — | Power net |
| 37 | EGR position | Differential (shared gnd 36) | `PTA15` | ADC1_SE12 | Hi-Z, no pull | |
| 36 | Sensor ground (EGR+oil) | Instrumentation-amp reference | — | — | — | Analog ground-plane net |
| 39 | Oil pressure 5V excitation | `5V_SENSOR` distribution | — | — | — | Power net |
| 80 | Oil pressure | Differential (shared gnd 36) | `PTA7` | ADC0_SE3 | Hi-Z, no pull | |
| 32 | Rail pressure 5V excitation | `5V_SENSOR` distribution | — | — | — | Power net |
| 35 | Rail pressure | Single-ended (dedicated gnd 08) | `PTA16` | ADC1_SE13 | Hi-Z, no pull | |
| 08 | Sensor ground (rail, dedicated) | — | — | — | — | Analog ground-plane net |
| — | `5V_SENSOR` rail monitor | Divider → ADC (spec §4's ratiometric-correction channel) | `PTC14` | ADC0_SE12 | Hi-Z, no pull | No connector pin — internal PCB net, required by the firmware ratiometric-correction scheme spec §4 already specifies |
| — | Onboard barometric sensor | New, per spec §7 deviation #2 | `PTD18` | ADC1_SE16 | Hi-Z, no pull | No connector pin — this is the 8th "sensor input" in memo 05's 14-channel ADC budget |

### 1.3 Speed

| ECU pin | Signal | Front-end | `PTxx` | Peripheral | Reset pull | Note |
|---|---|---|---|---|---|---|
| 52 / 74 | Crank VR High/Low | Differential adaptive-threshold conditioner (`vr_conditioner.cir`) | *(conditioner input, no direct MCU pin)* | — | — | The conditioner's zero-cross comparator already collapses this to one digital edge stream — see next row |
| — | Crank conditioner output | Zero-cross comparator output, ±198 mV hysteresis (`hw/speed_inputs.kicad_sch`) | `PTB2` | FTM1_CH0 (input capture) | Hi-Z, no pull | **Forced in kind, not in pin**: whatever pin is chosen must be FTM/capture-capable; `PTB2` is a free choice among many valid options. FTM configured for both-edge capture, per RM's `CnSC[ELSA:ELSB]` |
| 30 | Crank sensor ground | Shield termination, ECU end | — | — | — | Ground/shield net |
| 45 | Cam Hall 5V excitation | `5V_SENSOR` distribution | — | — | — | Power net |
| 46 | Cam frequency I/P | 10 k pull-up to `5V_SENSOR` **+ 16 k to ground**, 22 nF, 3.3 V zener (`cam_frontend.cir`) | `PTB3` | FTM1_CH1 (input capture) | Hi-Z, no pull | **CORRECTED 20 Sep 2026** — spec §4's literal "pull-up to `5V_SENSOR`" overvoltages the pad. See §4 |
| 44 | Cam sensor ground | — | — | — | — | Ground net |
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

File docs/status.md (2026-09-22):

# Build Status — What Is Done and What Is Not

**As of 20 September 2026, end of session.** Counts in this document are generated from the repository,
not maintained by hand: the block results come from `sim/run_sim.py`, the unknowns from
the specification's own register.

---

## At a glance

| | Count |
|---|---|
| Circuit blocks simulated | **24** |
| Blocks passing every check | **24** |
| Blocks failing a check | **0** |
| Research memos | **12** |
| Documents in the bible | **18** |
| Unknowns closed | **4** |
| Unknowns partly answered | **4** |
| Unknowns still open | **9** |
| Phase | **2** — schematic capture **complete**: 10 sheets, root wired, project netlist checked |

**All 24 blocks pass.** On 19 September it was 16, after a temperature-corner pass found
six blocks that fail cold or hot and turned prose caveats into enforced checks. All six
are now answered, and the answers are part specifications rather than widened checks —
every one of them is written up in `docs/bom_requirements.md` with the block that demands
it, and every failing corner is kept as pinned evidence of *why* the requirement exists.

**One of the six was not a part-selection problem at all.** The metering unit's coil is
copper, copper moves 0.39 %/°C, and no better resistor exists to buy. It needed closed-loop
current control, which put a 50 mΩ shunt and a sense amplifier on ECU pin 88's return —
new schematic content, not a BOM line. See §1.7.
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

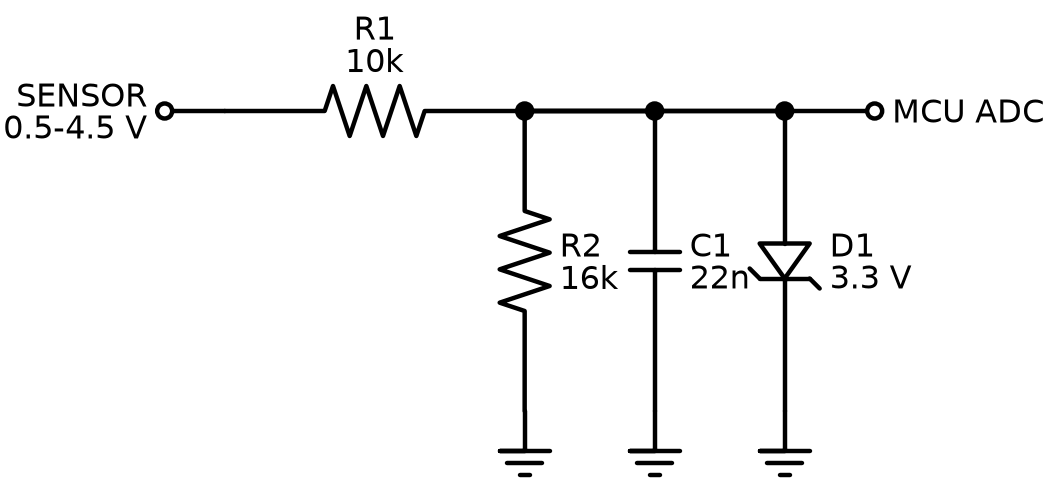
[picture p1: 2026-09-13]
docs/handbook/circuits/sensor_ratiometric.png

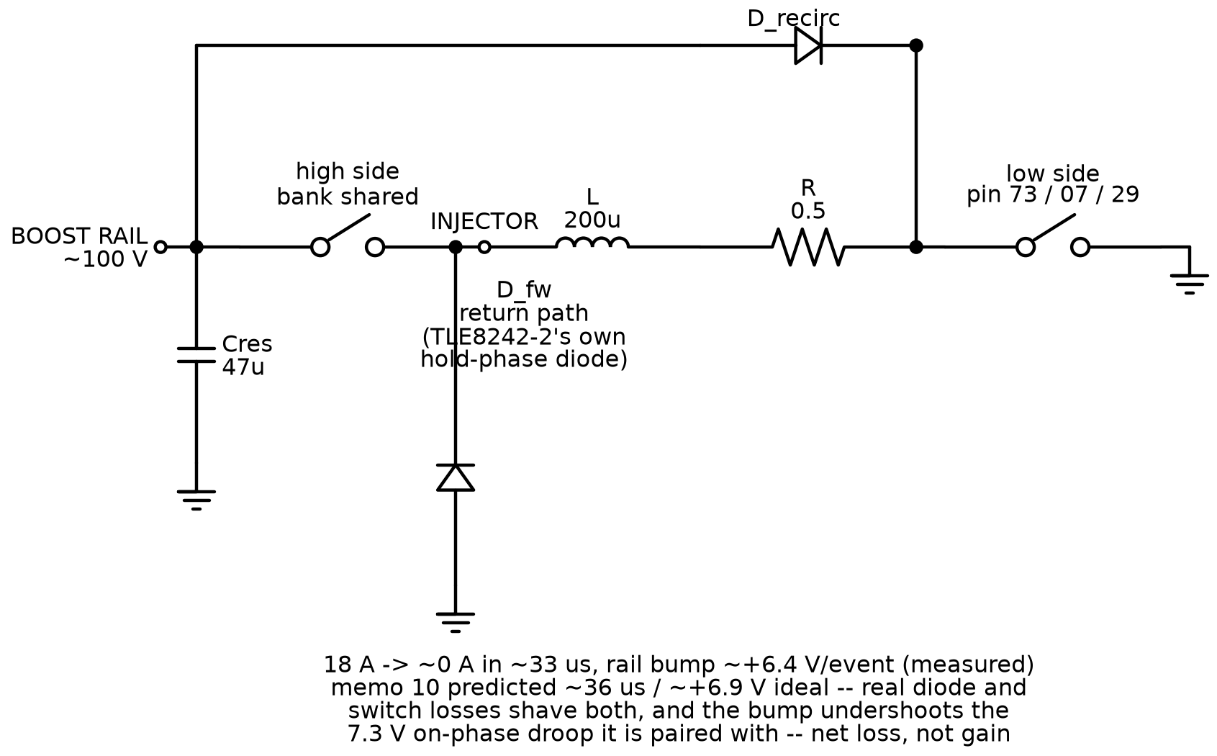
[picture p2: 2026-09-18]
docs/handbook/circuits/injector_turnoff.png

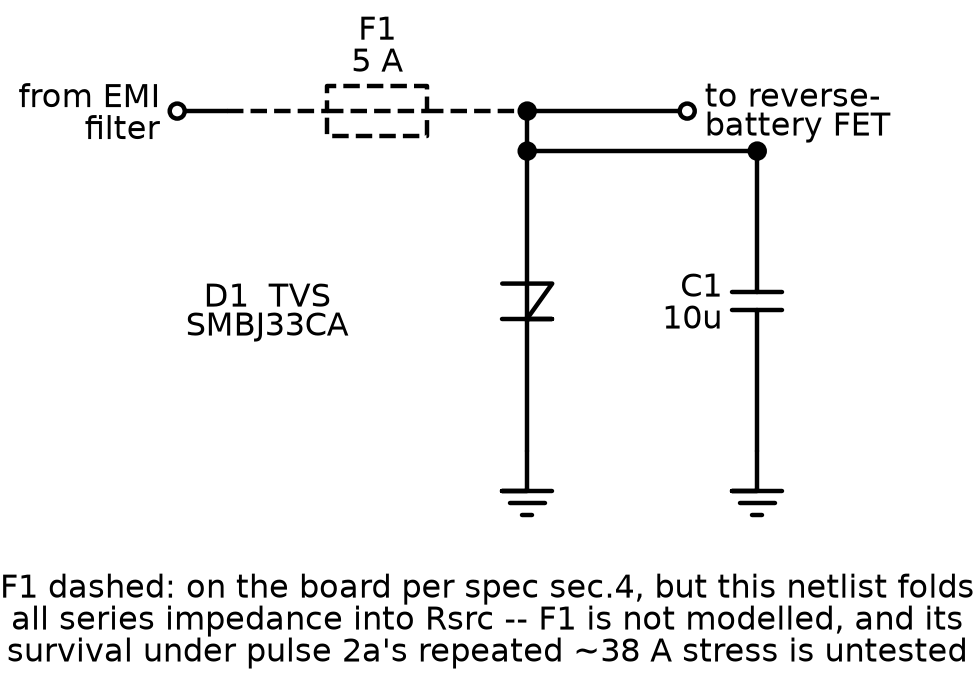
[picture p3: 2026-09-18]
docs/handbook/circuits/transient_clamp.png

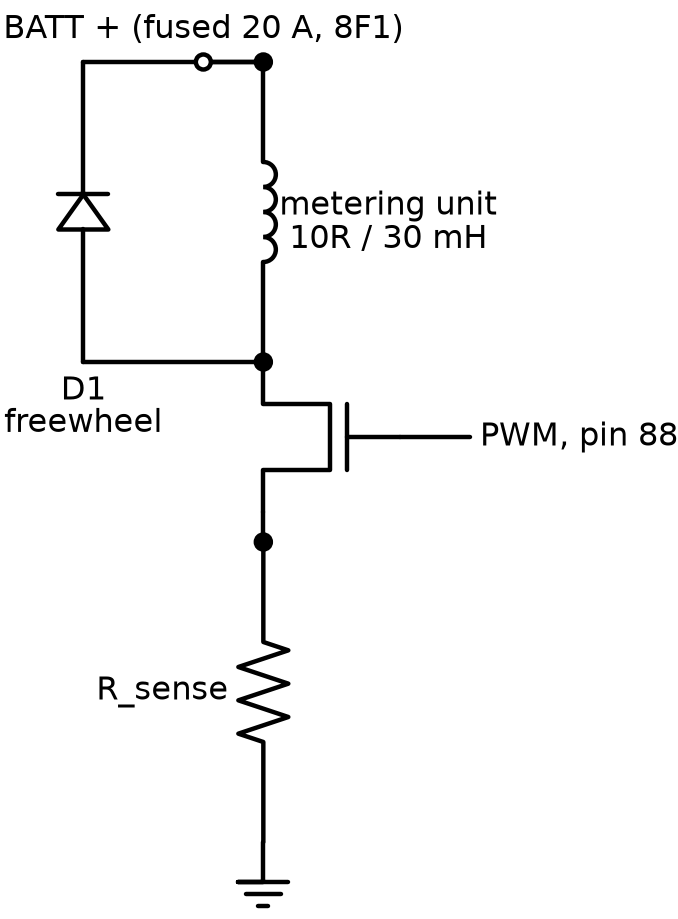
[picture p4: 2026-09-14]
docs/handbook/circuits/metering_unit_pwm.png

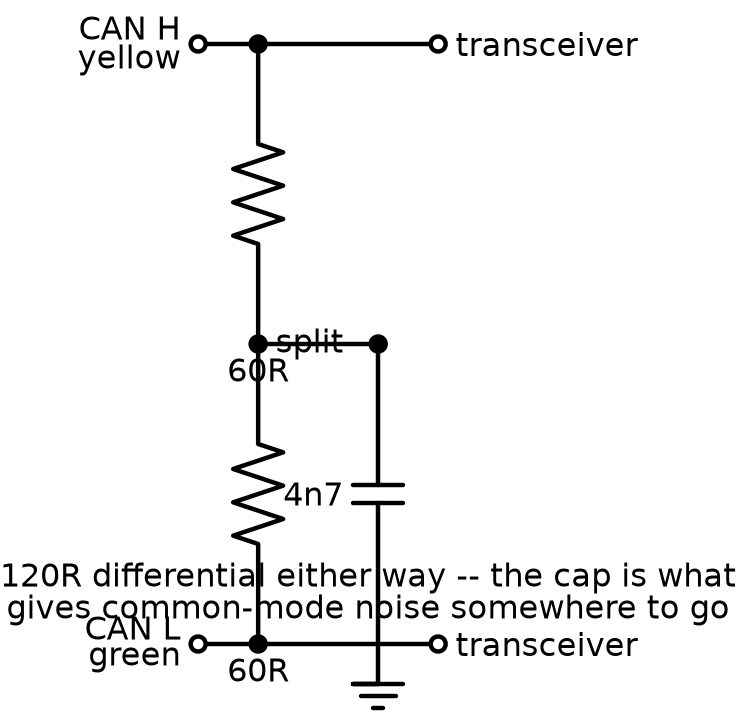
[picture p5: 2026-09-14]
docs/handbook/circuits/can_termination.png

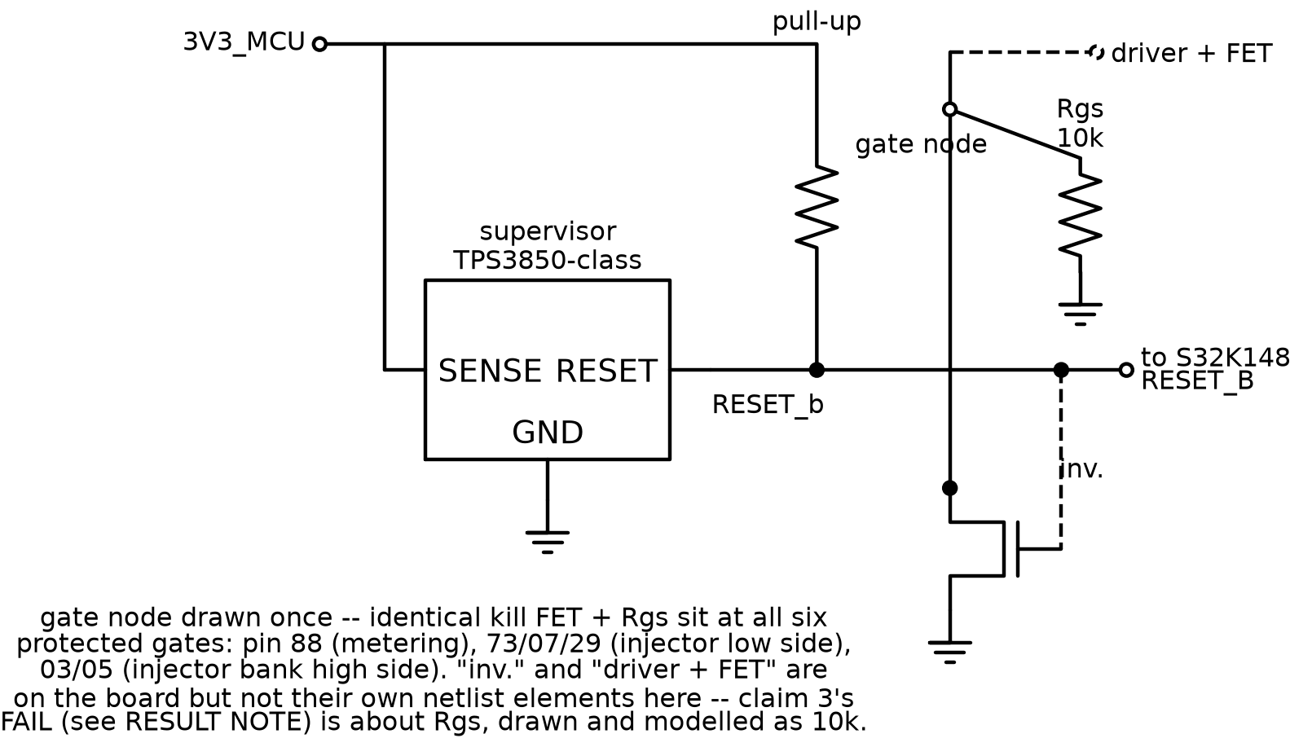
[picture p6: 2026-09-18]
docs/handbook/circuits/supervisor.png

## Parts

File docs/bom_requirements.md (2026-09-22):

# BOM requirements

What the schematic has to buy, and the simulation that says so.

Every row here exists because a block in `sim/blocks/` failed without it.
The rule this file follows is the same one the netlists follow: **a figure
nobody has read in a datasheet does not become a design number.** So these
are requirements stated as specifiable, purchasable properties — tempco
bands, ESR bands, on-resistance ceilings — not manufacturer part numbers.
Naming a part is a separate step, and it needs a retrieved datasheet.

Where a part number *does* appear below, it is because it was checked.

---

## Input protection

### `TVS` — transient suppressor, battery input

**SMCJ43CA.** Bidirectional, 43 V standoff, 1500 W package.

Both halves of that were forced by simulation, not chosen:

- **43 V standoff** is the smallest standard bin above the 40 V clamped
  load dump. Below it the part conducts during a *normal* ISO 7637-2
  pulse 5b event rather than a fault — which is what `load_dump.cir` was
  failing on, not "the TVS is too small."
- **1500 W (SMC) package, not 600 W (SMB).** At the SMB size, pulse 2a
  clamps at 88.6 V against the buck's 100 V absolute maximum — 11% margin.
  The SMC part has roughly half the dynamic resistance at the same
  standoff and clamps at 73.3 V, 1.37×.

Checked by `load_dump.cir` (0.000 A, 0.000 J through the TVS) and
`transient_clamp.cir`.

### `NEG-CLAMP` — negative active clamp, buck VIN

N-channel MOSFET, **Vds ≥ 80 V (100 V class), Rds(on) ≤ 10 mΩ at
Vgs = 4.5 V**, source to ground, drain to VIN, driven by a comparator
sensing VIN against a −0.1 V threshold. **In parallel with** the
100 V / 20 A clamp Schottky, which stays as the instant passive backstop.

> **CORRECTED 22 September 2026 — both parts were under-rated for the
> rail they sit on.** This tag originally read **Vds ≥ 40 V** and the
> backstop Schottky was **60 V**. Both have a terminal on `VBAT_PROT`,
> and both were sized for the *negative* pulses they exist to catch — but
> pulse 2a drives the **same node to +73.3 V**, where a 40 V FET is
> 0.55× rated and a 60 V Schottky 0.82×. The 40 V FET had zero margin
> on the 40 V load dump alone. `transient_clamp.cir` already carried the
> rule "every part on VBAT_PROT must clear 73.3 V" — as a principle, not
> a list, so nothing compared these two against it. It is now a table in
> `run_sim.py`: every part with a terminal on this rail, its rating, and
> the margin, and a part below the line fails.

The requirement is really an *effective clamp impedance*, and it is worth
stating as one: the LM5164's VIN absolute maximum is −0.3 V, pulse 1
delivers 150 V through 10 Ω, so

    Rclamp ≤ 0.3 V / 15 A = 20 mΩ, junction drop included

**No junction device meets that**, and the reason is structural rather
than a sizing miss. Decomposing the Schottky's own drop at 15 A:

| term | value |
|---|---|
| junction, `N·Vt·ln(I/Is)` | 0.367 V |
| bulk, `I·Rs` | 0.180 V |
| **total** | **0.547 V** |

Only the bulk term falls when parts are paralleled; the junction term is
logarithmic in current and barely moves. Four Schottkys in parallel still
leave 0.375 V. A FET in its ohmic region has no junction offset at all —
15 A through 5 mΩ is 75 mV.

Checked by `negative_pulses.cir`: buck VIN reaches −0.068 V on pulse 1
(4.4× inside the rating) and −0.027 V on pulse 3a (11×), against −0.528 V
and −0.393 V with the Schottky alone.

**Closed 22 September 2026 — and closing it found a latch the block had
been reporting as a pass.**

The control is **TLV3201-Q1** (50 ns max, push-pull, no phase inversion
beyond the rails) into **UCC27517A-Q1** (4 A, 23 ns max at 12 V, output
held low in UVLO). The comparator's 52 mA would take about half a
microsecond to charge the clamp FET's gate; the driver takes nanoseconds.

**The clamp is a low-side ideal diode, and it has to let go.** The model
engaged it near VIN = +0.08 V and released it only above +0.12 V. At the
end of every negative pulse the source returns to +13.5 V and drives
current back through the still-on clamp — 1.35 A through 5 mΩ is 6.7 mV,
never reaching the release threshold — so **the clamp latched on and
shorted the source for the rest of the run.** `run_sim.py` checked only
the clamp branch's *minimum* and reported it RESOLVED. A recovery check
added the same day failed against it on both pulse 1 and pulse 3a. With a
real battery instead of the test generator's 10 Ω, that is a dead short
after the first negative pulse.

The thresholds are now **engage below −100 mV, release above −6.8 mV**,
from the drawn network and checked as arithmetic against it:

| | |
|---|---|
| sense node | 10 kΩ from VIN, 499 kΩ from 5V_MAIN: 0.9804·VIN + 98.2 mV, so −100 mV arrives as 0 V and no negative reference is needed |
| reference | 10 kΩ to ground, **536 kΩ** from the output: 0 V low, 91.6 mV high |
| release, worst case | −6.8 mV nominal, **−1.8 mV** with the comparator's full 5 mV offset — still below zero, so it cannot hold on against reverse current (523 kΩ, the first value, sat at +0.5 mV) |

**The window before it engages is now a number, and it is inside the
rating.** With the ~100 ns delay (50 + 23 ns max plus gate charge) and a
10 ns timestep cap, VIN crosses −100 mV, keeps falling ~90 ns, and
bottoms at **−0.177 V** — inside the LM5164's −0.3 V by **1.70×**. The
Schottky backstop barely conducts. The previous −0.068 V / 4.4× was
optimistic by 2.6×: at the default step, ngspice committed the
hysteretic switch on a rejected trial step and hid the dip.

**Supplies are the power-up argument.** The comparator runs from
5V_MAIN, which is dead whenever VIN is too low to run the buck — so it
cannot hold the clamp on and short an incoming battery. The driver runs
from 12V_GATE, held up ~400 ms by the boost reservoir, so the clamp keeps
its gate through a whole pulse.

### Clamp Schottky

**100 V / 20 A class** — it was 60 V; see the correction above. It
carries what the TVS used to: **13.58 A peak, 14.5 mJ** on pulse 1,
measured at its own ammeter in `negative_pulses.cir` rather than inferred
from 150 V / 10 Ω.

A 100 V Schottky has a higher forward drop than the 60 V part
`negative_pulses.cir` models (`SCHN`, BV = 60 V). That drop only matters
for the comparator's propagation delay — the window before the active
clamp engages — and is re-measured when the comparator is chosen.

### Reverse-battery FET

**P-channel, |Vds| ≥ 80 V, Rds(on) ≤ 40 mΩ at Vgs = −4.5 V**, drain to
the battery side, source to the load, with a **passive gate network**:
47 kΩ gate-to-ground and a 12 V zener gate-to-source.

> **CORRECTED 22 September 2026 — the sheet had drawn an N-FET, and
> `reverse_battery.cir` has always modelled a P-FET.** Its header says
> "a P-FET held on by a controller that watches the polarity", and its
> switch model closes on positive polarity. Found while choosing the
> controller the N-FET would have needed.

**No controller IC checked can sit on this node.** It swings from
**+73.3 V** (pulse 2a, after the TVS) to **−47.8 V** (pulse 1, the
bidirectional TVS's negative clamp — bidirectional precisely so a
reversed battery does not forward-bias it). That is a 121 V span:

| Controller | Rated | Fails by |
|---|---|---|
| LM74700-Q1 | ANODE −65 V to **+65 V** | 8.3 V on the positive side |
| LM5050-1-Q1 | IN **−0.3 V** to +100 V | 47.5 V on the negative side — and IN draws 320 µA, so a series resistor to protect it corrupts its 20 mV sense |

A P-FET needs no controller: `Vgs = −V(load)`, so it is on whenever the
load side is positive and off when it is pulled to zero. That **is** the
block's switch model, with no IC ratings on a 121 V swing to violate.

**What it gives up, recorded rather than hidden.** An ideal-diode
controller blocks reverse *current*; this blocks reverse *polarity*. On
a dropout that *shorts* the input, bulk capacitance discharges backward
through the FET. The spec carries no hold-up requirement, and the
negative clamp is already sized for this FET staying on through a whole
pulse — its turn-off via 47 kΩ and `Ciss` takes tens of microseconds.

The 40 mΩ ceiling gives 0.2 V at 5 A against the block's 0.3 V
requirement. The model's 8 mΩ is its header's own "mid-range for a 100 V
P-channel" and is optimistic; the ceiling is what `run_sim.py` checks.

---

## Power

### `PDN-BULK` — 3V3_MCU bulk capacitor

**Polymer** aluminium electrolytic or polymer tantalum, 150 µF, specified
by an **ESR band of 20–50 mΩ across −40…+125 °C** — not by a 25 °C
typical figure.

Three things about that are load-bearing:

- **The part class changes, not the value.** A wet aluminium or tantalum
  electrolyte loses conductivity as it freezes, roughly 4× ESR at −40 °C,
  which puts the PDN peak at 197 mΩ against a 100 mΩ target. A solid
  polymer electrolyte has no such mechanism.
- **The cold number is what gets specified.** A supplier's 25 °C ESR does
  not answer this block's question, and asking for it is how the original
  corner got in.
- **A band, not a ceiling.** Bulk ESR is also what damps the
  regulator-against-bulk resonance. At 20 mΩ the peak climbs back to
  92 mΩ, 8 mΩ under target. "ESR ≤ 50 mΩ" would be satisfied by a 5 mΩ
  part that fails this block.

The 100 mΩ target is derived — 50 mV allowed ripple over a 0.5 A
transient step — not a round convention. Checked by `mcu_pdn.cir`.

### `SENSOR-PTC` — 5 V sensor rail, one per sensor group

Resettable PTC, hold current ≥ 200 mA, **R25 = 3.0 Ω nominal**.

Sized against the ceiling rather than guessed. The polyfuse has to be
what clears a shorted harness, not the 5 V regulator's own current limit,
so fault current must stay under 3.0 A:

    I < 3.0 A  ⟹  Rsrc + Rptc > 5/3 = 1.667 Ω
    corner = R25 × 0.8 (cold) × 0.7 (−30% spread) = 0.56 × R25
    ⟹  R25 > 2.78 Ω

At the same stacked −40 °C + −30% corner the specified part draws 2.88 A,
0.12 A under the ceiling. The larger series resistance was re-checked
against the rest of the block rather than assumed harmless: healthy-group
voltage holds at 4.69 V against a 4.5 V floor, and nominal fault current
stays inside the 0.3–3.0 A window the polyfuse needs to trip on.

Checked by `sensor_rail.cir`.

---

## Drivers

### `MU-ISENSE` — metering unit current sense, ECU pin 88 return

**50 mΩ shunt** on the low side, into **either** a current-sense amplifier
feeding an ADC channel **or** a gate driver with an integrated
current-regulation comparator.

The amplifier is not optional: 50 mΩ at the 0.675 A setpoint is 33.75 mV,
too small to take straight to the S32K148's ADC at useful resolution.

This one is not a part-selection fix at all — it is an architecture
change, and it is the only failing corner in the suite that no component
choice could have answered. The coil is copper, copper moves 0.39%/°C,
and over −40…+125 °C its resistance goes 7.39 → 13.82 Ω. At a fixed 50%
duty the mean current follows it: **0.862 A cold against 0.462 A hot**,
+27% and −32% around the setpoint. There is no better resistor to buy.

A hysteretic current regulator holds 0.679 / 0.679 / 0.683 A at
−40 / 25 / +125 °C. **Closed loop only works while the regulator has duty
left** — at the hot corner the coil can draw at most 13.5/13.82 = 0.977 A
at 100% duty, so the setpoint sits at 69% of the ceiling. That bound is
checked, because a regulator out of headroom degrades silently back to
open-loop behaviour rather than reporting anything.

Checked by `metering_unit_pwm.cir`.

### `EGR-DRIVER` — EGR H-bridge

A bridge driver with **internal DIR/PWM decode** — one logic input pair
that cannot express both legs of a diagonal conducting at once.

Two logic lines wired straight to two diagonal switch pairs short the
bridge: with both inputs asserted it draws **270 A**. Under a decoded
interface the same input combination draws **4.35 A**, the motor's own
stall current. The fault state stops existing rather than being avoided
by firmware convention.

Current capability: headroom over a 2.6–6.4 A stall.

> **Drawn 22 September 2026 — discrete, two `AUIRS2184STR`.** No
> integrated bridge clears the rail: DRV8873-Q1, the candidate, has a
> 40 V VM absolute maximum against 73.3 V, and the class caps at
> 40–45 V. So four **100 V** N-FETs (≤ 20 mΩ, headroom over the 6.4 A
> stall), and the decode this tag requires comes from the **driver's
> structure** rather than a logic gate: AUIRS2184S has **one input per
> leg** — IN high puts HO on, IN low puts LO on — with cross-conduction
> prevention and ~400 ns deadtime. Each leg's high and low are exclusive
> by construction, so the 270 A state, both inputs high, becomes a
> **high-side brake**.
>
> | EGR_EN | IN1 IN2 | bridge |
> |---|---|---|
> | high | 1 0 / 0 1 | forward / reverse |
> | high | 1 1 / 0 0 | high-side / low-side brake |
> | **low** | any | **COAST** |
>
> **Coast is asserted by copper.** Both drivers' SD̄ share `EGR_SD`,
> pulled down 10 kΩ, so with `PTB10` Hi-Z at reset both legs are off and
> the return spring closes the valve. A kill FET on the same node gives
> coast on `GATE_KILL` without the MCU. One 20 mΩ shunt in the shared
> low-side return feeds an INA181A1-Q1: 2.56 V at a 6.4 A stall.
>
> Pinout and logic are from the IR2184 datasheet (same die) and the
> AUIRS2181(4)S family table; **the automotive part's own datasheet was
> not retrieved** — confirm against it at sourcing.

Checked by `egr_hbridge.cir`, which keeps the naive wiring as pinned
evidence of why the requirement exists.

### `GATE-PULLDOWN` — fail-safe gate pulldowns, six driver gates

**470 Ω**, gate to source, on every driver gate.

The largest standard value that still holds a gate below Vgs(th) = 1.0 V
against Miller coupling at Crss = 500 pF. The commonly-reached-for 10 kΩ
fails even at the *low* end of the memo's own Crss envelope — 1.155 V at
50 pF already exceeds the threshold.

Cost, stated because it is real: 21.3 mA per gate held at 10 V, 1.28 W
across all six.

Checked by `supervisor.cir`.

---

## Signal

### `CAN-TERM` — CAN split termination, Rah / Ral

60.0 Ω **thin-film**, initial tolerance **±0.1%** or better, tempco
**±50 ppm/°C** or better.

Ordinary standard-grade thick-film runs 100–200 ppm/°C. At 200 ppm/°C
over the full −40/+125 °C span, both resistors shifting together, the
differential impedance reaches 123.95 Ω against J1939's own 120 Ω — and
120 Ω here is what the standard specifies, not a round convention, so
missing it is a real finding.

The contrast is a part class, with no meaningful cost or availability
penalty at this quantity. With both mechanisms stacked the adverse way
(60 × 1.00825 × 1.001 = 60.5555 Ω) the specified part lands at 121.10 Ω,
inside the ±2 Ω window with 0.90 Ω to spare. Checked at the **worst
case**, not the nominal — so passing means the requirement is sufficient,
not merely that it helps.

Checked by `can_termination.cir`.

### `VR-CLAMP` — crank input clamp diodes, four off

Reverse leakage **≤1 µA at 125 °C**. Forward drop is explicitly *not* a
requirement.

This inverts the rule every earlier clamp on this board was chosen by.
The negative-clamp Schottky's 0.547 V at 15 A decomposes into a junction
term and a bulk term, and that decomposition is what ruled out
paralleling junction devices for the power path. These four diodes
conduct only on a fault, into a 4.7 kΩ series resistor that is already
doing the limiting — what matters is what they do when they are **off**.

A reverse-biased diode's leakage flows out of the 4.489 kΩ Thévenin at
the comparator input and appears there as an offset voltage, against a
hysteresis window of ±198 mV:

| Class | Leakage at 125 °C | Offset | Against the window |
|---|---|---|---|
| BAT54S-class Schottky | ~200 µA (≈2 µA at 25 °C, ~100× hotter) | 0.90 V | **4.5× the whole window** — latches |
| BAV199-class low-leakage silicon | <1 µA (5 nA max at 25 °C) | <4.5 mV | 2% of the window |

The two diodes on a leg are reverse-biased symmetrically by `VR_BIAS`,
and the legs are matched, so leakages partly cancel and what survives is
partly common-mode. That is not a thing to defend a speed input on, so
the requirement is stated instead.

`vr_conditioner.cir` does **not** model this — its comparator is an ideal
switch with no input network, so no clamp, no leakage and no offset exist
in it. Found while drawing `hw/speed_inputs.kicad_sch`.

The same tag covers the **differential TVS across the pair**: bidirectional,
standoff ≥48 V. The standoff has to clear the *signal*, not just the rail
— VR amplitude is proportional to speed, about 20 V peak at 1500 rpm, so
a 24 V part would clip a runaway engine's own crank signal at the one
moment the ECU most needs to keep counting teeth. 48 V clears 3600 rpm.

### `VR-COMP` — crank zero-cross comparator

Single **3.3 V** supply, **push-pull** rail-to-rail output, propagation
delay **≤1 µs**. Input common-mode range: **mid-rail only**.

> **Chosen 22 September 2026: `TLV3201AQDCKRQ1`** — the same part as the
> negative clamp's comparator, so one part number serves both. 2.7–5.5 V,
> push-pull, input range (VEE) − 0.2 V to (VCC) + 0.2 V, **50 ns max**
> against the 1 µs requirement, 5 mV offset against a ±198 mV window.

Three of those four requirements are unusually easy, deliberately:

- The output swing *is* the hysteresis window (3.3 V × 4489/(4489+33000)
  = 0.395 V), so an open-drain part would make the window depend on its
  pull-up value and its V<sub>OL</sub>.
- Biasing the floating VR coil to `VR_BIAS` means the inputs never leave
  mid-rail, so **no common-mode range including ground is needed** — the
  usual hard constraint on a zero-cross detector, avoided by biasing the
  sensor rather than level-shifting it.
- 1 µs is 0.009 crank degrees at 1500 rpm on a 60-tooth wheel.
- Input offset voltage and its tempco are non-issues: 10 mV is 5% of the
  window.

Checked by `vr_conditioner.cir`, which establishes the topology (a fixed
5 V threshold produces edges at 1500 rpm and **none** at cranking speed)
and the ±0.2 V window the E24 network above lands on.

### `BOOST-BLEED` — injector boost reservoir bleed

**22 kΩ, 1 W**, across the 47 µF / 100 V reservoir.

The charger regulates from **one side only**: `boost_converter.cir`'s
`Bchg` adds 50 mA while the rail is below setpoint and adds nothing
above it. Nothing else in the circuit can remove charge, so any
excursion above 100 V is permanent. `injector_turnoff.cir` measured the
mechanism that produces one — a hold-current cutoff, whose energy came
from the **battery** through the high side's diode-OR and so has no
boost-side draw to net against — and its RESULT NOTE asked for this
resistor by name.

Sizing is not a duty-cycle argument; it is "one event is gone before the
next cylinder fires":

| | |
|---|---|
| event charge | 10 A decaying to 0 over 20 µs = 100 µC |
| on 47 µF | 2.14 V of rail rise |
| above setpoint | charger is **off**, so the whole 100 V / 22 kΩ = 4.55 mA discharges it |
| time to clear | **21.4 ms**, against **26.67 ms** between cylinders at 1500 rpm |
| cost | **455 mW**, burned continuously whenever the rail is up |

Checked by `boost_converter.cir` arrangement C, which runs two identical
reservoirs — one bare, one bled — through three such events at the real
cylinder spacing. Bare, the rail stacks to 106.4 V and stays there.

A comparator-gated shunt costs nothing at idle and is the alternative.
It is more parts, and it is a part nobody has chosen.

**Over a complete injection event there is no pumping at all** — the
peak phase draws 342 µC from the reservoir and end-of-injection
recirculation returns roughly 100 µC of it. This resistor is not there
for normal running. It is there because one-sided regulation has no
answer for an excursion from *any* cause.

### `INJ-RECIRC` — injector recirculation diodes, five off

**150 V, 20 A, ultrafast.** Three on the low sides (one per cylinder,
into the boost reservoir) and two on the high sides (the battery
diode-OR).

Research memo 10 names the class. Not a Zener active clamp across the
FET — Nexperia AN50003 rates repetitive active clamp
reliability-"Questionable" for gate-oxide wear-out. Not a bare freewheel
to battery, which is too slow: the same problem the boost rail exists to
fix on the opening side.

**Sized by the pulse, not the average.** `injector_turnoff.cir` measures
28.7 W instantaneous during turn-off against roughly 3.6 W averaged over
all nine events per second — a factor of eight. The average would never
have sized this part.

---

## Chosen parts

These are the entries that have moved from "a class" to "a part number",
each against a datasheet that was actually retrieved and read. They are
listed separately from the requirements above because they are answers,
not constraints.

| Function | Part | Why this one |
|---|---|---|
| Buck pre-regulator | **LM5164DDAR** | 100 V input, 1 A, 6–100 V range. See below — it replaces a 60 V part that can no longer survive this input. |
| 3V3 regulator | **TLV76733QWDRBRQ1** | 1% over load *and* temperature. The supervisor makes that load-bearing. |
| Supervisor | **TPS3850G33DRCT** | ±4% window variant, so its undervoltage trip clears the MCU's own LVD by 143 mV rather than 44 mV. |
| Injector boost controller | **TPS40210QDGQRQ1** | Chosen on its **200 ns maximum off-time** — the one spec that makes 94% duty reachable at the 6 V cranking corner. See below. |
| Gate drivers, all eight gates | **AUIRS2181STR** ×5 | **No cross-conduction interlock** — the injector's high and low switches are in series with the coil and must both be on. See below. |
| Difference amplifiers | **INA592IDR** ×5 | Native G = ½, 88 dB CMRR min against a 60 dB floor the discrete network could not reach. **Not AEC-Q100** — see below. |
| Barometric sensor | **MPXHZ6115A6T1** | Spec §7 deviation 2, on-PCB behind a vented port. AEC-Q100 **not stated** in its datasheet — see below. |
| EGR bridge drivers | **AUIRS2184STR** ×2 | One input per leg: each leg's high and low exclusive by construction. See `EGR-DRIVER`. |
| Negative-clamp control | **TLV3201AQDCKRQ1** + **UCC27517AQDBVRQ1** | A low-side ideal diode: engage below −100 mV, release above −6.8 mV. See `NEG-CLAMP`. |
| Current-sense amplifiers | **INA181A1QDBVRQ1** ×3 | VCM reaches −0.2 V, so it sits across a ground-referenced shunt; supplied from 3V3_MCU so its output is ADC-safe by construction. |
| Kill FETs and reset inverter | **2N7002BK** ×10 | 60 V, ±20 V Vgs, Vth 1.1–2.1 V, 2 Ω max at Vgs 5 V against the 5 Ω `supervisor.cir` assumes. AEC-Q101. Needs `GATE-KILL-CLAMP`. |
| GATE_KILL clamp | **BZX84-C12-Q** | 11.4–12.7 V at 5 mA, +10 mV/K max. AEC-Q101. The plain BZX84 series is no longer automotive-qualified; the `-Q` suffix is. |
| Relay FETs | **PMV280ENEA** ×2 | 100 V, ±20 V Vgs, 432 mΩ max at Vgs 4.5 V. AEC-Q101. Driven through a buffer — see `RELAY-GATE`. |
| Relay gate buffers | **CAHCT1G125QDBVRQ1** ×2 | SN74AHCT1G125-Q1 on 5V_MAIN: VIH 2 V reads a 3.3 V GPIO, VOH 4.4 V min drives the FET. AEC-Q100. |
| Reverse-battery FET | **SQD50P08-25L** | −80 V P-channel, ±20 V Vgs, 31 mΩ max at −4.5 V against a 40 mΩ ceiling. AEC-Q101, TO-252. |
| 100 V N-channel | **IPD90N10S4-06** ×8 | Negative clamp, metering, four EGR, two injector battery switches (60 V class needed; one part number instead of two). 6.7 mΩ max at 10 V, ±20 V Vgs, AEC-Q101, TO-252. The logic-level sibling `-S4L-06` was rejected for its ±16 V Vgs: every one of these gates is driven from 12V_GATE. |
| Injector 150 V FETs | **SQM85N15-19** ×5 | Two boost-side high sides, three low sides. 19 mΩ max at 10 V — the model's 20 mΩ. ±20 V Vgs, AEC-Q101, TO-263. Qg 120 nC max sets the bootstrap droop: 126 mV. |
| Boost switch | **DMN15H310SK3** | 150 V, Vth 3 V max, 350 mΩ max at Vgs **4 V** — specified below the 5.7 V it gets while cranking. Qg 8.7 nC typ. AEC-Q101, TO-252. Cranking duty with its drop, hot: 94.8% against 97.0% available. |
| Injector recirculation, blocking, freewheel | **VS-16EDH02HM3** ×7 | 200 V, 16 A avg, 250 A surge, trr 32 ns, AEC-Q101. SMPD (TO-263AC): **no KiCad 7 footprint — drawn in phase 3.** Average current per diode is tens of mA; the rating is for the 18 A peaks. |
| Boost diode | **VS-2EMH02HM3** | 200 V, 2 A, trr 25 ns, AEC-Q101, SMA. |
| Bootstrap and relay flyback diodes | **VS-1EMH02HM3** ×8 | 200 V, 1 A, 50 A surge, AEC-Q101, SMA. The relay flybacks needed only 100 V; one part number instead of two. |
| Metering freewheel | **VS-3ECH02HM3** | 200 V, 3 A, 130 A surge, AEC-Q101, SMC. |
| Negative-clamp backstop Schottky | **SS20PH102HM3** | 100 V, 20 A, 310 A surge, AEC-Q101, TO-277A. Stock footprint puts the cathode on pad 3; the project's `TO-277A_K1_A2` renumbers it (`hw/gen_footprints.py`). |
| Battery TVS | **SMCJ43CA-HM3** | 43 V standoff, 47.8–52.8 V breakdown, 69.4 V clamping at 21.6 A, 1500 W, AEC-Q101. |
| Crank-pair TVS | **SMAJ48CA-HE3** | 48 V standoff, 53.3–58.9 V breakdown, 400 W, AEC-Q101. |
| 12 V clamps | **BZX84-C12-Q** ×2, **BZX84-C13-Q** | GATE_KILL, reverse-FET gate, 12V_GATE reference. SOT-23 with pin 3 as the cathode, so the project's `SOT-23_Zener_K1_A2` footprint is used. The GATE_KILL zener's first footprint, the stock SOT-23, had its anode where the symbol puts the cathode. |
| VDD clamp | **BZG03C36-HM3** | See `BOOST-VDD-CLAMP`: it replaced a 43 V clamp that did not clamp. |
| Buck inductor | **Würth 7447714330** | WE-PD 1050, 33 µH, Isat 2.9 A typ against a 1.18 A worst peak (1.72× after a −30% hot derate), 79 mΩ, AEC-Q200 Grade 1. This closes the Isat gap `buck_preregulator.cir` left open. Land pattern not in KiCad 7. |
| 12V_GATE pass / limit | **PZTA42-Q**, **PMBT3904-Q** | See `GATE-RAIL`. PMBT3904-Q is SOT-23 B-E-C, so it uses the `Q_NPN_BEC` symbol. |

### `PASSIVE-PACKAGES` — 188 resistors and capacitors, sized by what is across them

`hw/assign_passives.py` gives every chip resistor and capacitor its
package, and `hw/check_netlist.py` fails if a part is added or
re-valued without re-running it.

The voltage comes first. Each net carries a continuous and a peak
voltage: battery nets are 24 V jump-start and 73.3 V pulse 2a, the
boost rail is 104 V. The voltage across a part is the worse of its two
nets, with two exceptions. Inside a bootstrap domain, a part sees only
the 13.6 V gate swing. And `PAIR_V` overrides the few series strings
and AC-only parts where "the worse net" over-states what is across
them. Both are keyed by net names, which is why several internal nodes
were given labels: the auto-names `Net-(R407-Pad2)` move whenever a
part is added ahead of them.

- **Resistors: Vishay D/CRCW e3 ratings** (AEC-Q200, standard mode).
  The peak voltage must clear Umax by the rail table's 1.09×. The
  continuous V²/R must fit the power rating derated to 0.588× at a
  105 °C board. Nothing is smaller than 0603.
- **Capacitors: KEMET C1023 X7R AUTO** (AEC-Q200). The rating must
  clear the peak voltage and 1.5× the continuous one, and nothing up to
  1 µF is rated below 25 V. The part picks the smallest case that
  KEMET's waterfall table actually lists at that rating. The table is
  parsed by x-coordinate into `hw/lib/kemet_x7r_auto.json`
  (`hw/tools/parse_kemet_waterfall.py`), because the PDF's text layout
  compresses the data columns and misreads them.

Result: 121 × 0603, 36 × 0805, 5 × 1206, 7 × 1210 and 12 × 2010, plus
the stated 2512 parts and the shunts.

Things this pass found:

- **4.7 µF at 100 V is not in the automotive X7R range**; 1210 stops at
  50 V. Three places needed it: the EMI filter's C1, the buck input and
  the boost input. Each is now two 2.2 µF, 100 V, 1210 parts.
  `emi_filter.cir` models the pair as 4.4 µF with ESR and ESL halved.
  Its cold corner is 0.6 dB worse, and the check was re-pinned.
- **The twelve 470 Ω gate pulldowns land in 2010.** At 100% duty
  (metering, EGR) 12 V across 470 Ω is 0.31 W per gate, as well as
  25 mA of driver current. They were sized for Crss = 500 pF, and the
  worst chosen FET is 300 pF, so 1 kΩ may now serve. That would need a
  re-run of `supervisor.cir` claim 6 before it could be claimed.
- **DC bias on bulk MLCCs is not modelled.** Two parts are affected:
  the 47 µF 10 V buck output and the 10 µF 6.3 V on 3V3_MCU. Both
  lose a large part of their capacitance at their working voltage. The
  1.5× rule does not capture that.

### `POWER-PATH` — what the input filter and reverse FET actually carry (OPEN)

Every high-current load on the board draws from VBAT_PROT: the injector
battery switches (10 A hold), the EGR bridge (up to 6.4 A stall) and
the relay coils. VBAT_PROT is fed through connector pin 21, then the
20 A fuse, the 22 µH + 0.5 µH EMI filter, the TVS and the reverse FET.
Two blocks sized parts on that path, and neither was written with this
load in mind:

- `reverse_battery.cir` states its claim at **5 A** (0.2 V).
- `emi_filter.cir` was written for the buck's 400 kHz noise and never
  states a DC current.

A 22 µH inductor that does not saturate at 15–20 A is a large part.

The connector has two more battery feeds, pins **04** and **06**
(`V_BAT_1R/2R`, each fused 10 A in the loom). The spec says they "feed
high-current loads [?]", and the board uses them only as ADC senses.
Moving the injector and EGR supply onto 04/06, with its own protection,
would leave pin 21 feeding the electronics: a few amps through the
filter. Keeping everything on pin 21 means resizing the filter, the fuse
and the reverse FET for the full load, and relying on one contact to
carry it.

**This is an architecture decision.** L101, L102 and F101 stay unchosen
until it is made.
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

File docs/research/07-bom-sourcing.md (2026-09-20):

# Research Memo 07: Consolidated BOM and Sourcing

**Task:** Consolidated, costed bill of materials covering every functional block in spec
§4 and §6. Consumes Tasks 3 (connector), 4 (injector driver), 5 (MCU) — the three hard
sourcing problems — plus the simulation-fixed component values supplied directly for
this task.
**Date:** 2026-09-13
**Author:** Phase-1 research (task 7)
**Scope note, stated once and binding throughout:** this ECU has no DEF/urea sensor, no
LIN bus, no SCR, no magnetic pickup, and one catalyst temperature sensor. Fuel level and
water-in-fuel are panel signals, not ECU signals. None of these appear below. Earlier
design artifacts that included them were wrong and are not carried forward.

---

## Read this first — the headline

| | Qty 1 | Qty 10 |
|---|---|---|
| **BOM total (excl. PCB fab, excl. assembly)** | **≈ ₹14,200** | **≈ ₹1,34,500** (≈ ₹13,450/unit) |

Two findings drive that number and its shape:

1. **The 94-pin OEM-mating connector is ~45–50% of the per-unit BOM cost, and it does
   not get cheaper with volume** — it is bought as an aftermarket wired-pigtail kit at a
   fixed per-kit price, not from a distributor with quantity breaks. This is the single
   biggest lever on total cost and the single biggest sourcing risk in the design.
2. Real quantity discounts on the catalog parts (MCU, injector driver, CAN transceiver,
   buck, supervisor) only partly show up at qty 10 — DigiKey's own price breaks for these
   lines mostly land at qty 100, not qty 10 — so the qty-10 total is not proportionally
   cheaper than 10× the qty-1 total.

**Single-source / long-lead lines flagged: 3 confirmed, 1 partially mitigated, 1 open
Phase-2 item.** See §3.

---

## 1. Method and honesty note

Per the task's own budget instruction, this memo prices the expensive and risky lines
from live or near-live distributor data — **MCU, injector driver, connector, CAN
transceivers, the buck** — and gives the remaining functional blocks a **reasonable
aggregate estimate, marked as such**, built from a named representative automotive-grade
part rather than an invented number with no anchor. Every "estimate" line is a candidate
part in a real, in-production automotive family, priced by class-typical India distributor
pricing, not fabricated from nothing — but it has **not** been individually fetched from
a live distributor page this session, and Phase 2 must confirm it before BOM lock.

Distributor pricing fetches in this session hit DigiKey India live pages successfully;
Mouser India pages timed out repeatedly (likely bot-mitigation, consistent with what
Memo 05 reported for Mouser/DigiKey chip pages). Where a Mouser-only line is cited, the
price is from search-indexed content, not a live page load, and is marked accordingly.

---

## 2. BOM by functional block

Legend: **AEC** = automotive qualification status. **C** = confirmed this session (live
fetch or direct citation). **I** = inferred / estimated, not independently priced this
session. Currency conversion where only USD was found: ₹88/US$1, noted per line.

| # | Functional block (spec §4/§6) | Part | Distributor | Stock | Qty 1 (₹) | Qty 100 (₹) | Lead time | AEC-Q | Status | Cite |
|---|---|---|---|---|---|---|---|---|---|---|
| 1 | EMI input common-mode choke | Würth WE-CMB automotive CMC (representative, e.g. 744232801-class) | Mouser/DigiKey (class-typical) | — | ~90 | ~55 | — | AEC-Q200 (passive) | **I** — aggregate estimate | class pricing, not fetched |
| 2a | Reverse-battery ideal-diode controller | TI **LM74610-Q1** | DigiKey / Mouser | listed | ~320 (est. from $1.25@1k) | ~140 | standard | AEC-Q100 | **I** — price scaled from confirmed $1.25@1000 unit | [TI](https://www.ti.com/product/LM74610-Q1) |
| 2b | Reverse-battery P-FET | Infineon **IPB80P03P4L-01** (representative AEC-Q101 P-FET) | Mouser/DigiKey (class-typical) | — | ~150 | ~90 | — | AEC-Q101 | **I** — aggregate estimate | class pricing, not fetched |
| 3a | Transient clamp — TVS | **SMBJ33CA** bidirectional TVS (fixed by simulation) | Mouser/DigiKey (widely stocked jellybean) | — | ~18 | ~8 | — | Commercial-grade common; automotive-grade (`-13-F` type suffixes) available from Littelfuse/Vishay/onsemi | **I** — aggregate estimate | class pricing, not fetched |
| 3b | Transient clamp — 10 µF bulk cap | Automotive X7R/electrolytic, 10 µF (fixed by simulation) | Mouser/DigiKey (class-typical) | — | ~15 | ~7 | — | AEC-Q200 (ceramic) | **I** — aggregate estimate | class pricing, not fetched |
| 4 | Buck pre-regulator, 6–40 V → 5 V | ~~TI TPS54360B-Q1~~ → **SUPERSEDED 20 Sep 2026, see the note under this table: TI LM5164DDAR** | DigiKey (global; India page not confirmed live) | listed | ~458 ($5.20 × 88) | ~280 (est.) | standard | AEC-Q100 | **C** (price), 60 V-rated device chosen over 42 V LM5175-Q1 for load-dump margin — **I** (India-specific stock/lead time not confirmed) | [DigiKey search](https://www.digikey.com) — $5.20/pc found via search index |
| 5a | `5V_SENSOR` LDO | TI **TLV70233-Q1**-class automotive LDO (representative) | Mouser/DigiKey (class-typical) | — | ~120 | ~70 | — | AEC-Q100 | **I** — aggregate estimate | class pricing, not fetched |
| 5b | `5V_SENSOR` PTC resettable fuses ×4 (per sensor group) | Bourns **MF-USMF**-class automotive PTC | Mouser/DigiKey (class-typical) | — | ~100 (4×~25) | ~60 | — | AEC-Q200 | **I** — aggregate estimate | class pricing, not fetched |
| 6 | `3V3_MCU` LDO | ~~TLV1117-33QDCYRQ1-class~~ → **SUPERSEDED 20 Sep 2026: TI TLV76733QWDRBRQ1** | Mouser/DigiKey (class-typical) | — | ~70 | ~35 | — | AEC-Q100 | **I** — aggregate estimate | class pricing, not fetched |
| 7 | Supervisor (windowed WD + BOR) | TI **TPS3823-33QDBVRQ1** | DigiKey India | 4,605 units in stock | **162.44** | **95.60** | Mfr. standard 16 wk (moot — stock covers near-term demand) | AEC-Q100 | **C** — live DigiKey India fetch | [DigiKey.in](https://www.digikey.in/en/products/detail/texas-instruments/TPS3823-33QDBVRQ1/1894636) |
| 8 | MCU | NXP **FS32K148HAT0MLQT**, 144-LQFP | DigiKey India | In stock, ships ~4 days (sibling SKU confirmed; exact SKU "ships today" per global listing) | **~1,950** (₹1,900–2,000 band) | ~1,400 (est., no qty100 break found) | Not a lead-time problem | AEC-Q100 | **C** — per Memo 05 | [Memo 05](./05-mcu-selection.md), [DigiKey](https://www.digikey.com/en/products/detail/nxp-usa-inc/FS32K148HAT0MLQT/8628226) |
| 9 | Crystal (MCU osc.) | NDK/Abracon AEC-Q200 automotive crystal, 8 MHz-class (representative) | Mouser/DigiKey (class-typical) | — | ~35 | ~18 | — | AEC-Q200 | **I** — aggregate estimate | class pricing, not fetched |
| 10 | CAN transceiver ×2 + protection | TI **TCAN1042HGVDRQ1** (×2) + ESD array (representative NUP2105L-class, ×2) | DigiKey India | **Out of stock; 2,500 units expected 21-Sep-2026** | **426.16** (2× 213.08) + ~40 (2× ~20 ESD) | **257.50** (2× 128.75) + ~30 | **Mfr. standard 16 weeks** | AEC-Q100 | **C** (transceiver price/stock) — **flagged, see §3** | [DigiKey.in](https://www.digikey.in/en/products/detail/texas-instruments/TCAN1042HGVDRQ1/5967638) |
| 11 | VR conditioner (crank sensor) | Melexis **MLX92242**-class or NXP MC33199-class differential VR interface (representative — not yet selected) | Mouser/DigiKey (class-typical) | — | ~180 | ~100 | — | AEC-Q100 | **I** — aggregate estimate, **part not yet firmly selected (Phase 2)** | class pricing, not fetched |
| 12 | EGR H-bridge | Infineon **TLE9201SG**-class automotive H-bridge (representative) | Mouser/DigiKey (class-typical) | — | ~220 | ~140 | — | AEC-Q100 | **I** — aggregate estimate | class pricing, not fetched |
| 13 | Metering-unit low-side driver + current sense | Infineon **BTS443P**-class automotive smart low-side switch (representative) | Mouser/DigiKey (class-typical) | — | ~250 | ~160 | — | AEC-Q100 | **I** — aggregate estimate | class pricing, not fetched |
| 14a | Injector driver IC | NXP **MC33816AE** | DigiKey India | **868 units** | **1,040.54** | **693.12** | Std.; note: page shows "Last Time Buy Date 06/08/2027" — **flagged, see §3** | Industrial/automotive SMARTMOS, not itself AEC-Q100-badged in fetched listing — **needs Phase-2 confirmation** | **C** — live DigiKey India fetch | [DigiKey.in](https://www.digikey.in/en/products/detail/nxp-usa-inc/MC33816AE/4693868) |
| 14b | Injector boost stage (65–115 V, 12–24 A pk, 8–13 A hold) | Discrete: boost controller (e.g. LM5155-Q1-class) + HV automotive MOSFETs + magnetics + HV caps | Mouser/DigiKey (class-typical, multi-part) | — | ~800 | ~500 | — | Mixed AEC-Q100/Q101 | **I** — aggregate estimate for the whole discrete stage, **no specific BOM chosen yet (Phase 2)** | Memo 04 envelope |
| 15 | Relay FETs ×2 (main relay, buzzer relay) — low-side N-FET + flyback diode each | Automotive N-FET (e.g. IPD50N04S4L-13-class) + automotive Schottky (e.g. SS34-class), ×2 pairs | Mouser/DigiKey (class-typical) | — | ~80 (2×~40) | ~40 | — | AEC-Q101 | **I** — aggregate estimate | class pricing, not fetched |
| 16 | Barometric sensor (onboard, per spec §7 deviation #2) | NXP **MPXH6115A6U**-class automotive absolute pressure sensor (representative) | Mouser/DigiKey (class-typical) | — | ~450 | ~300 | — | Automotive-grade family (NXP MPXH line is automotive-qualified) | **I** — aggregate estimate, **part not yet firmly selected (Phase 2)** | class pricing, not fetched |
| 17a | 94-pin ECU-mating connector (adapter harness side) | **Bosch EDC17-style 94-pin + 60-pin companion, wired pigtail kit** — leading candidate, unconfirmed part number | u-obd.com / ecudepot.com / autoecupart.net (aftermarket ECU-repair trade) | Listed, multiple sellers | **~6,600** (US$65–99 × 88, band) | **~6,600** (no bulk break — aftermarket kit pricing) | Order-dependent, international shipping + India customs, **not independently verified — Phase 2 item** | N/A — not a distributor part number | **C** (price band at source) / **I** (India-landed total) — **flagged, see §3** | [Memo 03](./03-ecu-connector.md), [u-obd.com](https://www.u-obd.com/product/edc17-connector/) |
| 17b | New ECU-side split connectors (spec §7 deviation #1) | TE Connectivity sealed automotive connector family (e.g. MCON 1.2/Superseal-class, representative) | Mouser/DigiKey (mainstream stock) | — | ~300 (aggregate, multiple housings) | ~180 | — | Automotive sealed connector family | **I** — aggregate estimate, exact housing/pin-count split not yet designed | class pricing, not fetched |
| 18 | Fixed-value passives (battery-sense divider ×2, discrete-input front-end ×3 sets, ratiometric front-end ×4 sets, plus generic bypass/pull-up passives) | 1% metal-film resistors, MLCC caps, zener diodes per the simulation-fixed values below | Mouser/DigiKey (class-typical) | — | **~300** | **~150** | — | Mixed AEC-Q200 (passive) availability | **I** — aggregate estimate, see breakdown below | class pricing, not fetched |

**Passives aggregate breakdown (line 18), values fixed by simulation, not re-derived:**
- Battery-sense divider, ×2 (pins 04, 06): 120 kΩ / 10 kΩ, 1% metal film — 4 resistors.
- Discrete-input front-end, ×3 (pins 20, 24, 71): 47 kΩ / 68 kΩ, 220 nF, 3.0 V zener — 12 components.
- Ratiometric sensor front-end, ×4 (boost pressure, EGR position, oil pressure, rail pressure): 10 kΩ / 16 kΩ, 22 nF, 3.3 V zener — 16 components.
- Plus an allowance for generic bypass caps, gate resistors, and pull-ups not individually itemized in this memo.
- ~32 fixed-value components + ~30 generic ones ≈ 60–70 small passives total, priced at India-typical qty-1 rates of ₹2–4/resistor, ₹3–6/MLCC cap, ₹8–15/zener; qty-100 rates roughly a third lower. This is the class of line the task explicitly authorizes as an honest aggregate rather than 30 invented individual prices.

---

### Superseded 20 September 2026, during schematic capture

Two rows above are struck through. Both were chosen honestly and both
have since been overtaken — one by a design change, one by a requirement
that did not exist when the table was written.

**Row 4, the buck.** TPS54360B-Q1 was picked as a 60 V part "for
load-dump margin" over a 42 V alternative. Correct at the time. The
input-protection work then raised the TVS standoff to 43 V, so the
suppressor stops conducting during a *normal* clamped load dump — and a
higher standoff clamps higher, putting the ISO 7637-2 pulse 2a clamp at
**73.3 V**. `sim/blocks/transient_clamp.cir` now carries a *passing*
check whose text reads "60 V-class parts are NO LONGER viable
downstream". A 60 V buck on this input fails the first pulse 2a event.

The replacement is **LM5164DDAR**, 100 V input, 1 A, 6–100 V range. It is
not a new candidate: it is the part every rating check in the simulation
suite has been written against since the negative-pulse work — its
−0.3 V / 100 V VIN limits are what `negative_pulses.cir` and
`transient_clamp.cir` check. The BOM table had simply never been
reconciled with the suite.

That gap is the lesson worth keeping from this row. **The contradiction
sat in the repository for days between an executable file and a prose
table, and only the executable one knew.** Nothing flagged it, because
nothing compares them; it surfaced when someone had to draw the buck and
needed a pinout.

**Row 6, the 3V3 LDO.** TLV1117-33QDCYRQ1 was listed as representative,
with its own caveat "class pricing, not fetched". Choosing the supervisor
(TPS3850G33, `docs/pinmap.md` §1.8) turned 3V3 accuracy into a hard
constraint: outside 3.143–3.459 V the supervisor resets the board. That
makes "representative" no longer good enough. **TLV76733QWDRBRQ1** is 1%
over load *and* temperature — 3.267–3.333 V, ~125 mV margin at each end.

Pricing for neither replacement has been fetched; the estimates in the
table above are stale for these two rows and should be re-costed before
BOM lock. Full reasoning and the derived configuration values are in
`docs/bom_requirements.md`.

## 3. Single-source and long-lead flags

Per the task's global instruction: any line with one supplier, or a lead time beyond
eight weeks, gets a named second source or an explicit "no alternative identified." These
are the lines that stall a build.

### 3.1 94-pin ECU-mating connector — FLAGGED, no distributor alternative identified

**Single-source in the distribution sense that matters:** the leading candidate (Bosch
EDC17-style 94-pin housing) is sold **only through the international ECU-repair
aftermarket** (u-obd.com, ecudepot.com, autoecupart.net, eBay sellers) — confirmed absent
from Mouser India, DigiKey India, and Element14 in Memo 03's search. That channel carries
real risks a normal distributor doesn't: no formal datasheet, counterfeit/quality risk,
order-dependent lead time, and customs/duty exposure not yet quantified.

**Named second sources, both weaker matches, both mainstream-distributor-buyable:**
- **Aptiv/Delphi GT-150 series** — Mouser-stocked, moderate visual match, exact 94-position
  variant not yet confirmed to exist (Memo 03, negative result on that specific check).
- **TE Connectivity AMPSEAL (90-series)** — Mouser/DigiKey-stocked, weakest visual match
  (oval/rounded shell vs. the drawing's rectangular multi-row grid), but the safest
  fallback if the Phase-2 photograph rules out the other two.

**This line cannot be closed further without the photograph brief in Memo 03 §4.** It is
the top risk item in this BOM — both for build-stalling potential and for the ~45–50% of
per-unit cost it represents.

### 3.2 Injector driver IC (MC33816AE) — FLAGGED, no alternative identified

Memo 04 searched specifically for allocation-free alternatives (Infineon TLE8090, Elmos
E526) and returned a **negative result** — no confirmed, small-quantity-orderable
alternative dedicated common-rail injector-driver IC was located. The MC33816AE is
**confirmed in stock (868 units) at DigiKey India** today, which is good news, but it is
a single-supplier (NXP), single-product-line dependency with no named second source.

**New finding this session, not yet resolved:** the live DigiKey India page for this part
carries a **"Last Time Buy Date: 06/08/2027"** field. Memo 04 separately reports the part
as "Active" under NXP's Product Longevity Program (a 10-year-availability commitment),
which is not the same thing as an EOL notice — a longevity-program part can still show a
programmatic LTB-style date without meaning the product is being discontinued. **This
memo cannot resolve which reading is correct with the sources available this session** —
it is flagged, not smoothed over, as a Phase-2 item: confirm directly with NXP or
DigiKey sales whether MC33816AE has an active EOL notice before committing the injector
driver architecture to this part.

**No alternative identified.** If the LTB field turns out to mean what it says, this
becomes the most urgent open item in the entire BOM, ahead of the connector.

### 3.3 CAN transceiver (TCAN1042HGVDRQ1) — FLAGGED, second source named

Live DigiKey India data this session: **out of stock**, with 2,500 units expected
2026-09-21, and a **manufacturer standard lead time of 16 weeks** — over the task's
8-week threshold on both counts (current stockout, and the manufacturer-quoted lead time
for a fresh order).

**Named second source:** NXP **TJA1051** / **TJA1042** high-speed CAN transceiver family
— AEC-Q100, functionally equivalent (ISO 11898-2 high-speed CAN transceiver), confirmed
listed at Mouser (Memo-05-style search-index confirmation; India-specific live price not
obtained this session, flagged as a Phase-2 confirmation item). Given the restock date
is roughly one week out, this may resolve itself before it matters, but the flag stands
per the letter of the instruction — it was out of stock and over 8 weeks lead time at
time of writing.

### 3.4 Supervisor IC (TPS3823-33QDBVRQ1) — flagged on paper, low real risk

DigiKey's manufacturer standard lead time field shows 16 weeks (>8-week threshold), but
**4,605 units are in stock right now** at DigiKey India, which resolves the practical
risk for any order size this project plausibly needs. Named second source anyway, for
completeness: Microchip **MCP130**-class or ON Semi automotive supervisor family, both
mainstream-distributor-stocked.
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

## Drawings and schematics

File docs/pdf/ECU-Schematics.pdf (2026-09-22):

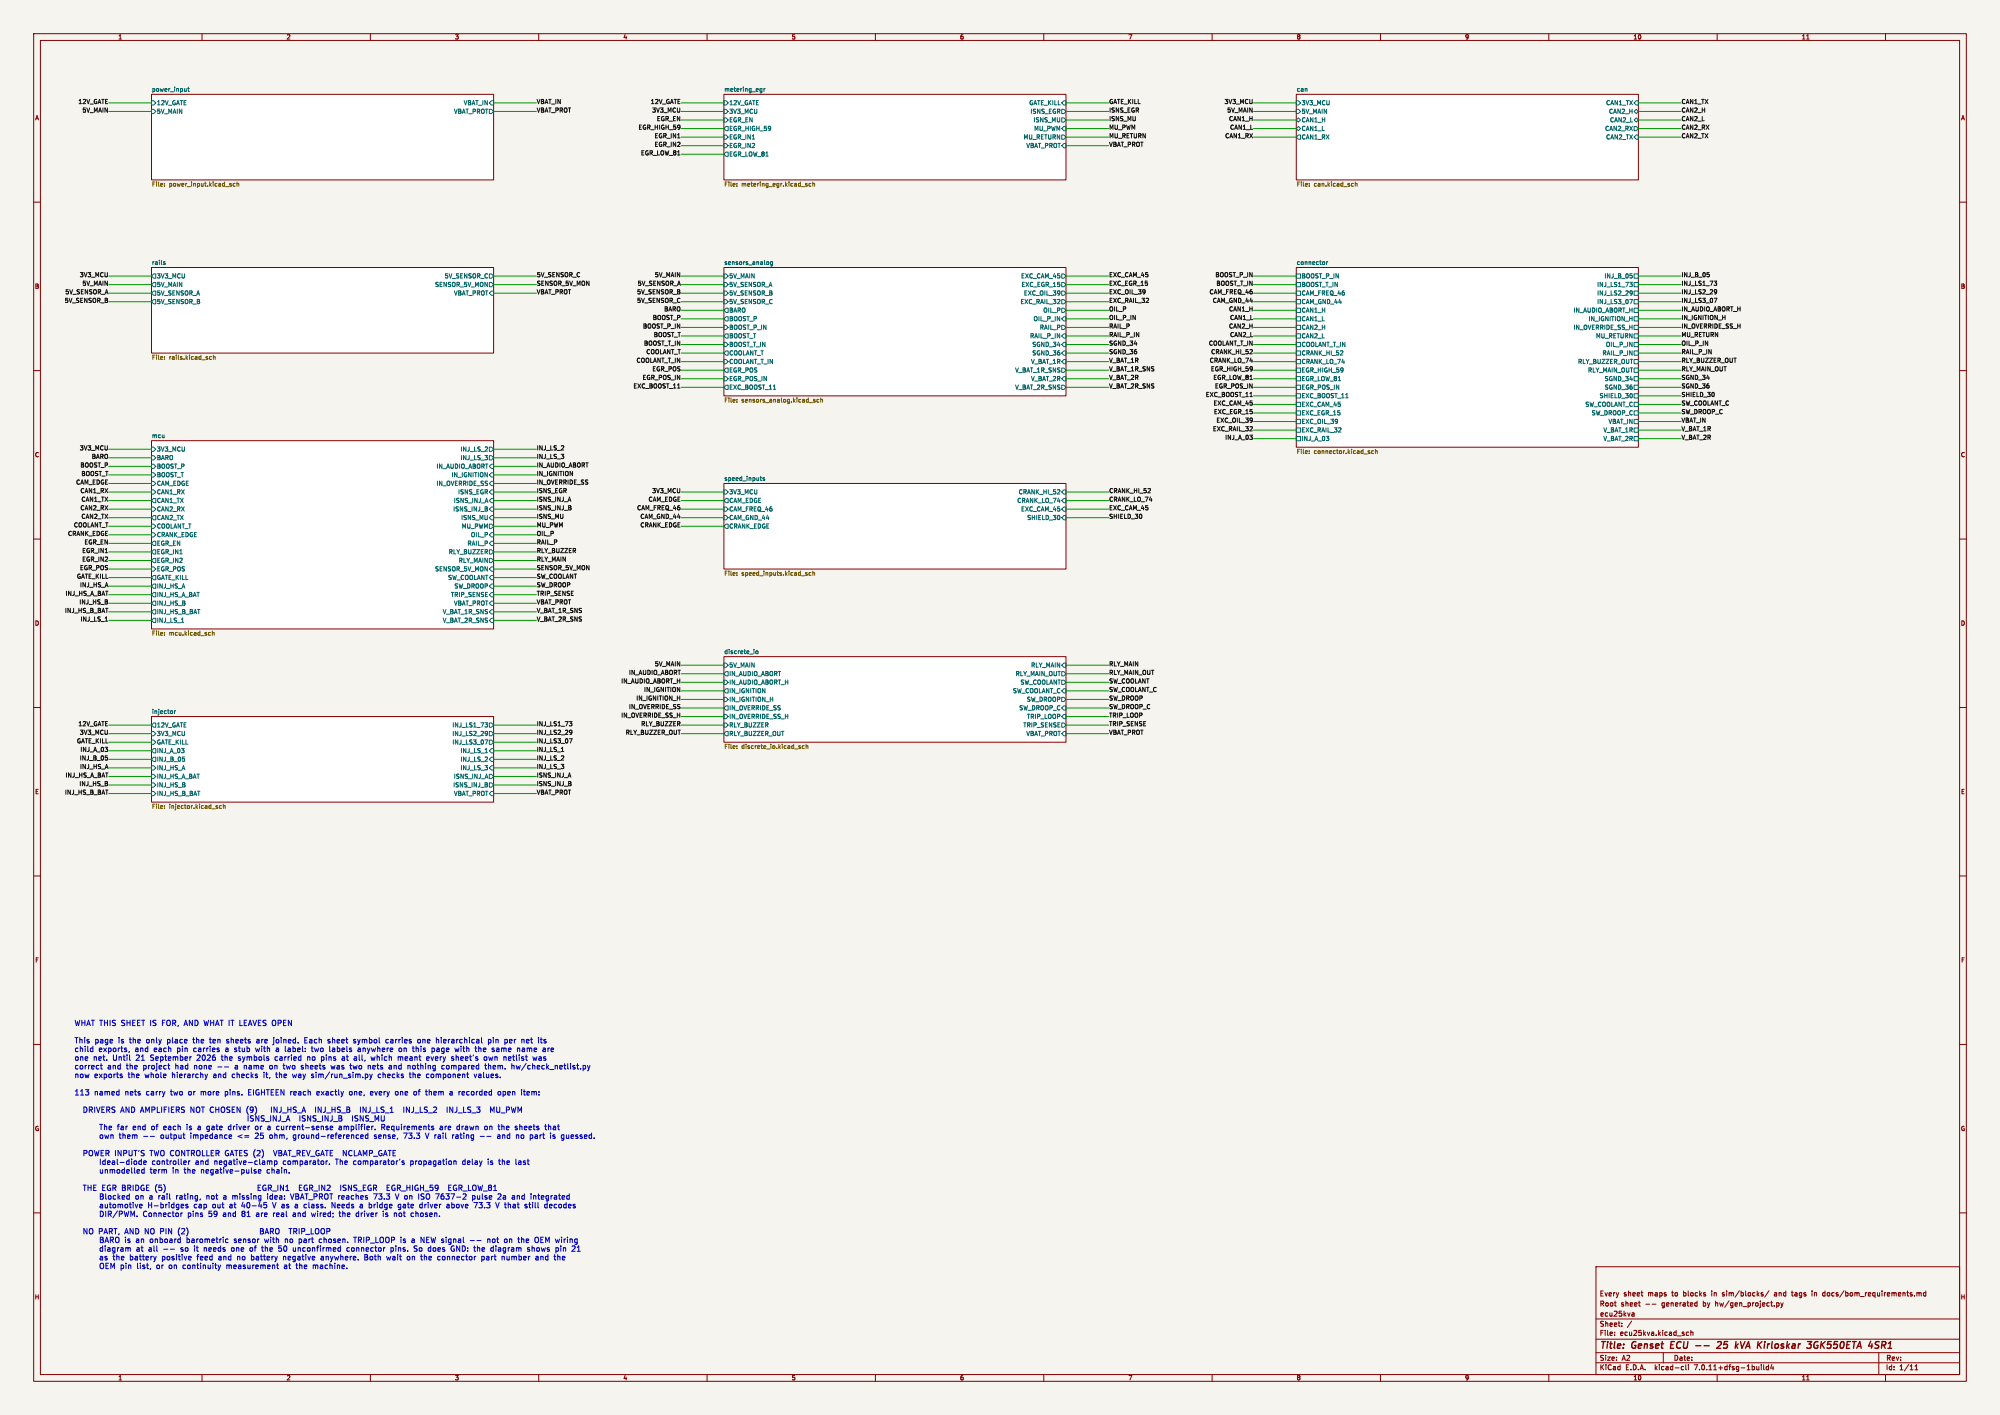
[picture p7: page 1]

WHAT THIS SHEET IS FOR, AND WHAT IT LEAVES OPEN

child exports, and each pin carries a stub with a label: two labels anywhere on this page with the same name are
one net. Until 21 September 2026 the symbols carried no pins at all, which meant every sheet's own netlist was

113 named nets carry two or more pins. EIGHTEEN reach exactly one, every one of them a recorded open item:

DIR/PWM. Connector pins 59 and 81 are real and wired; the driver is not chosen.

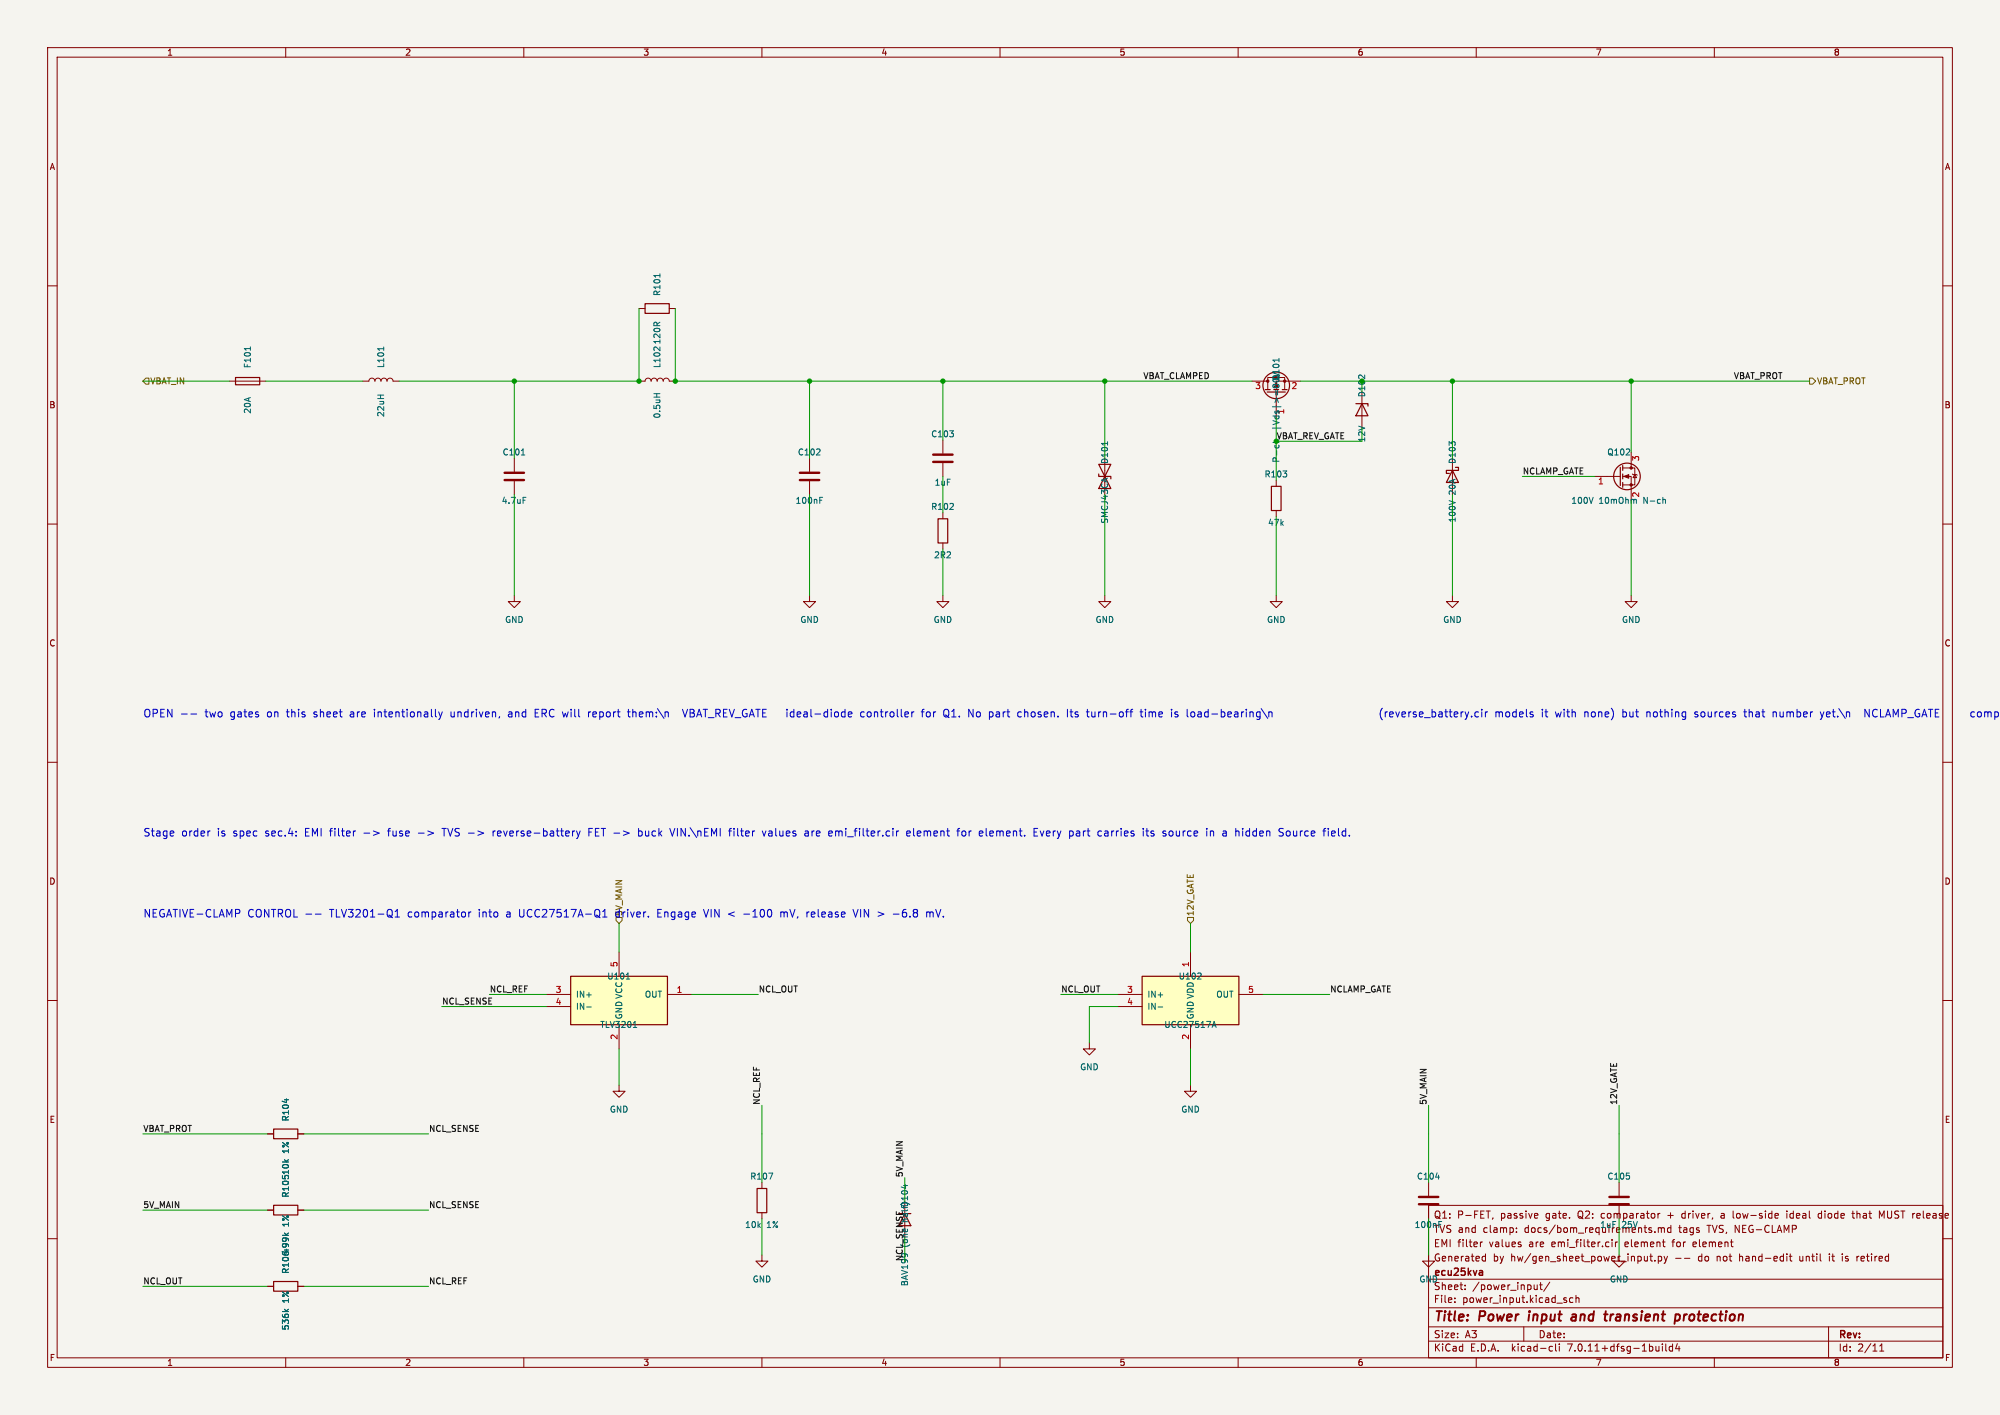
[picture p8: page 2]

Id: 2/11 Title: Power input and transient protection

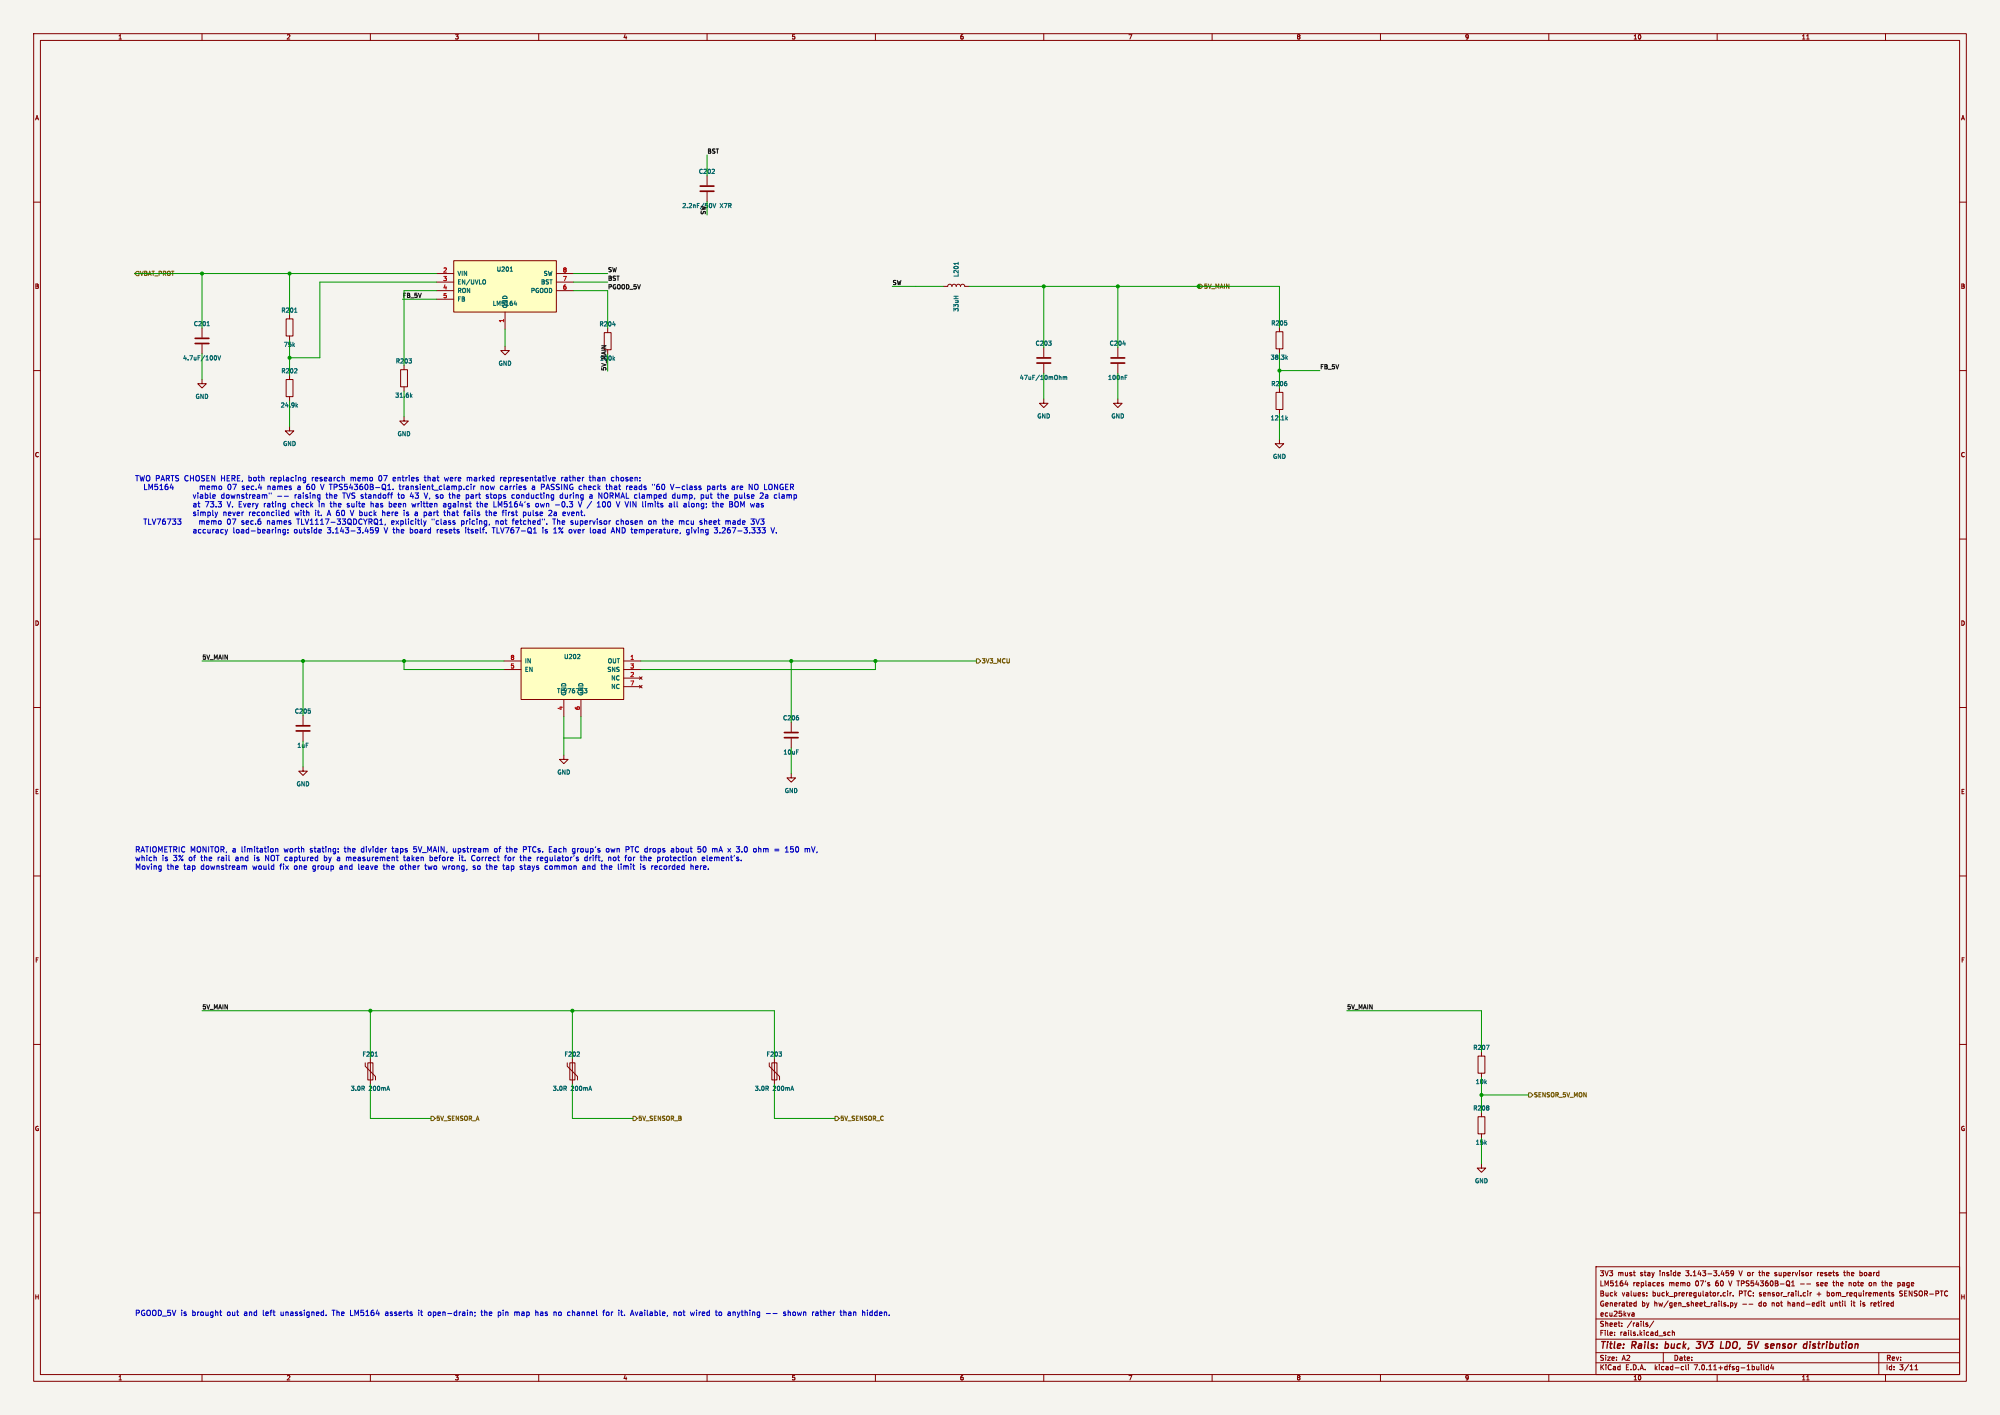
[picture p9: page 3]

1 VIN 2 EN/UVLO 3 RON 4 FB 5 PGOOD 6 BST 7 SW U201 8

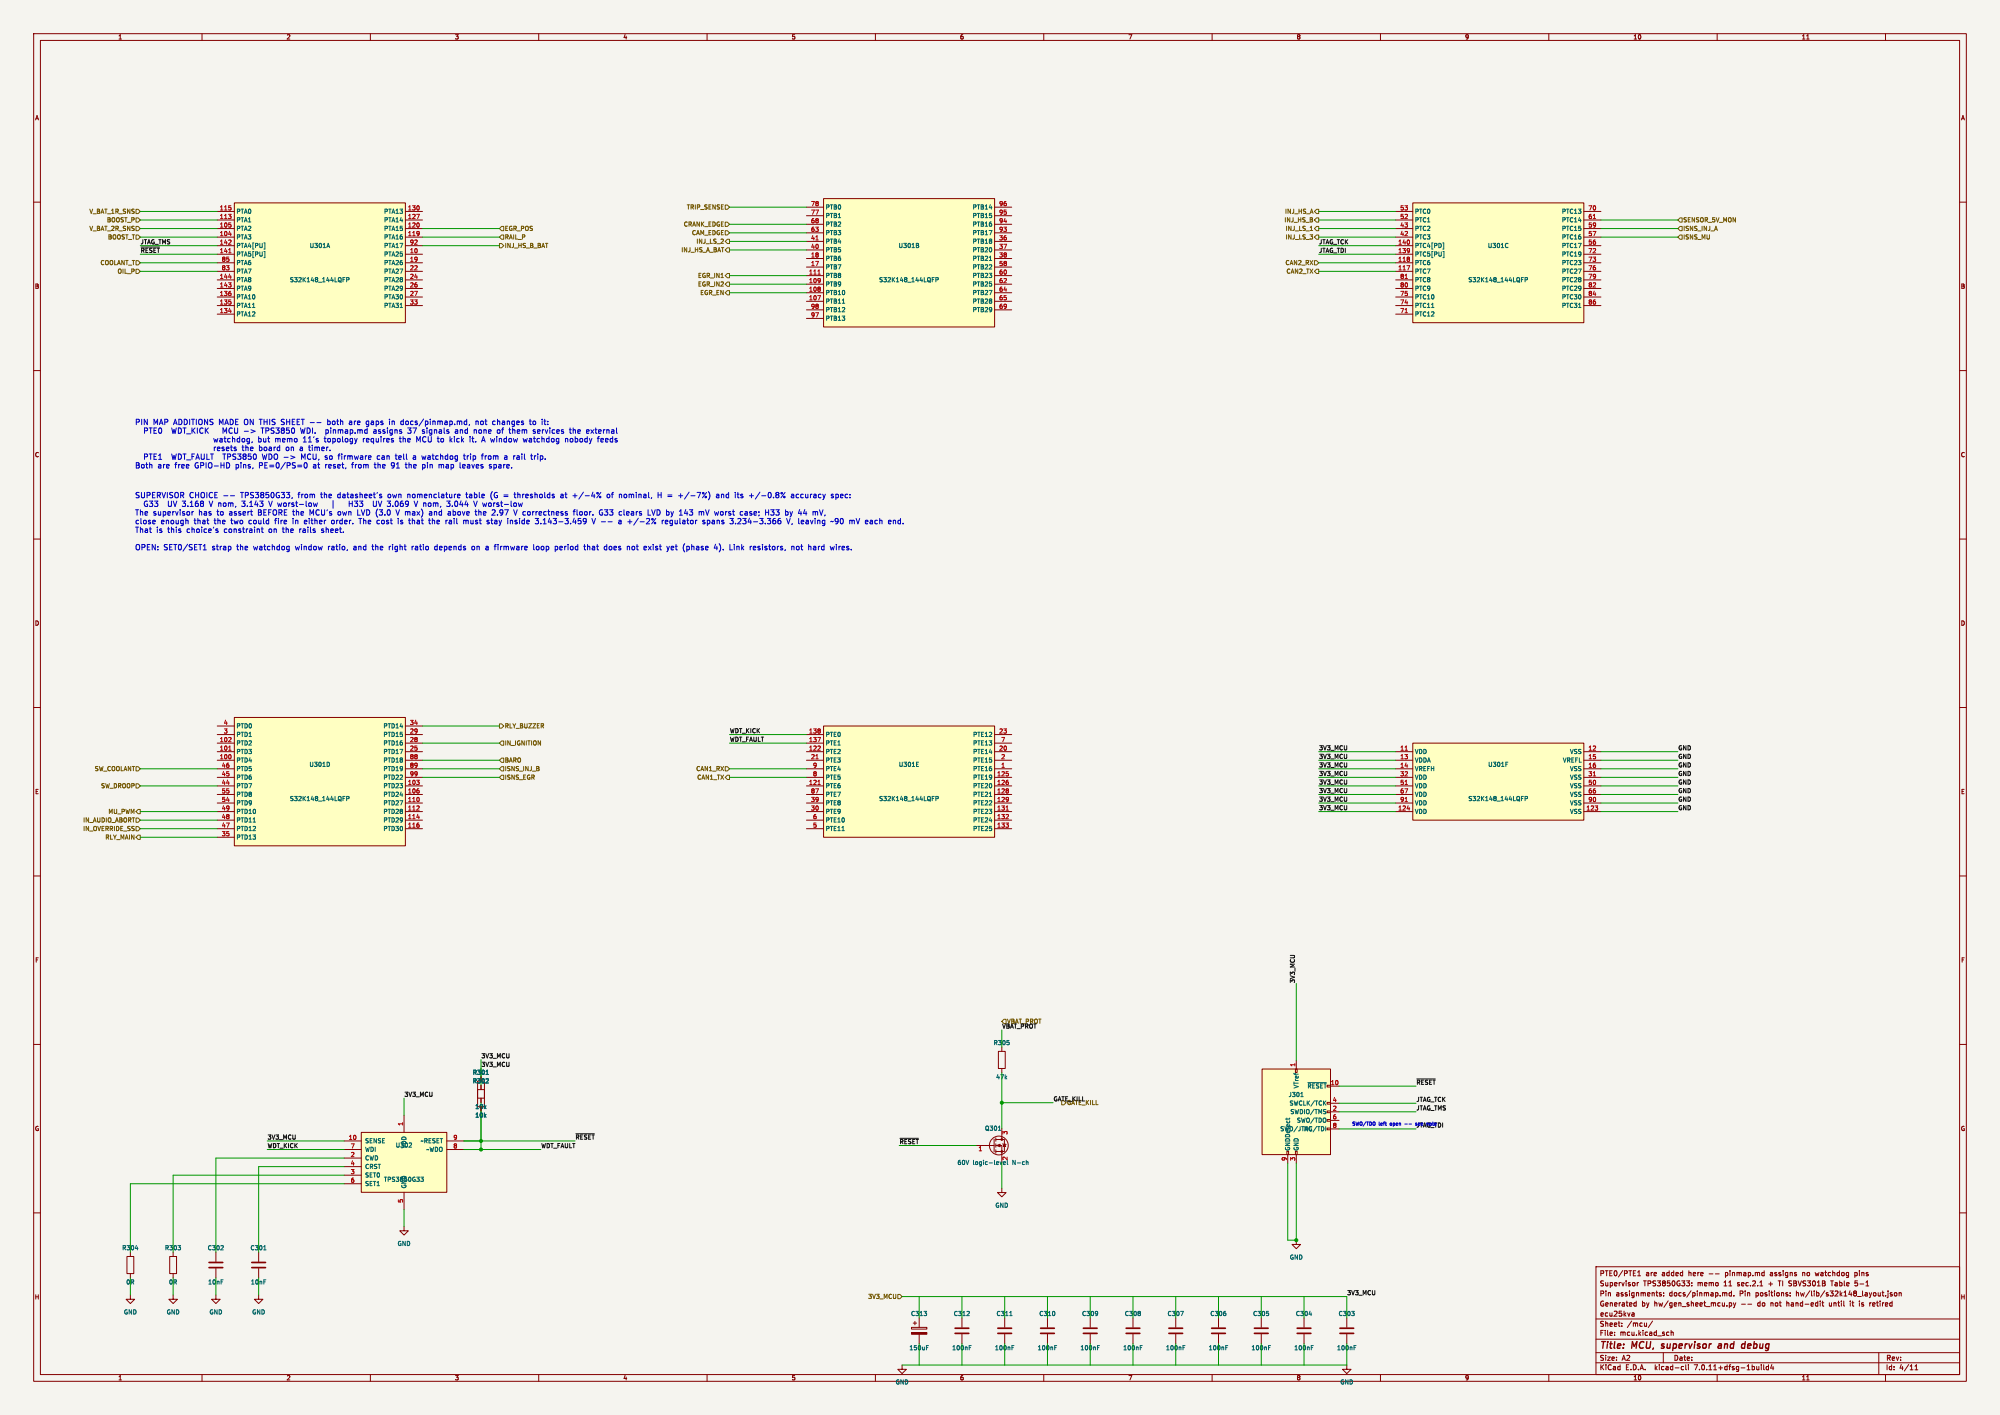
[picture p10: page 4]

resets the board on a timer.

1 SENSE 10 CWD 2 SET0 3 CRST 4 GND

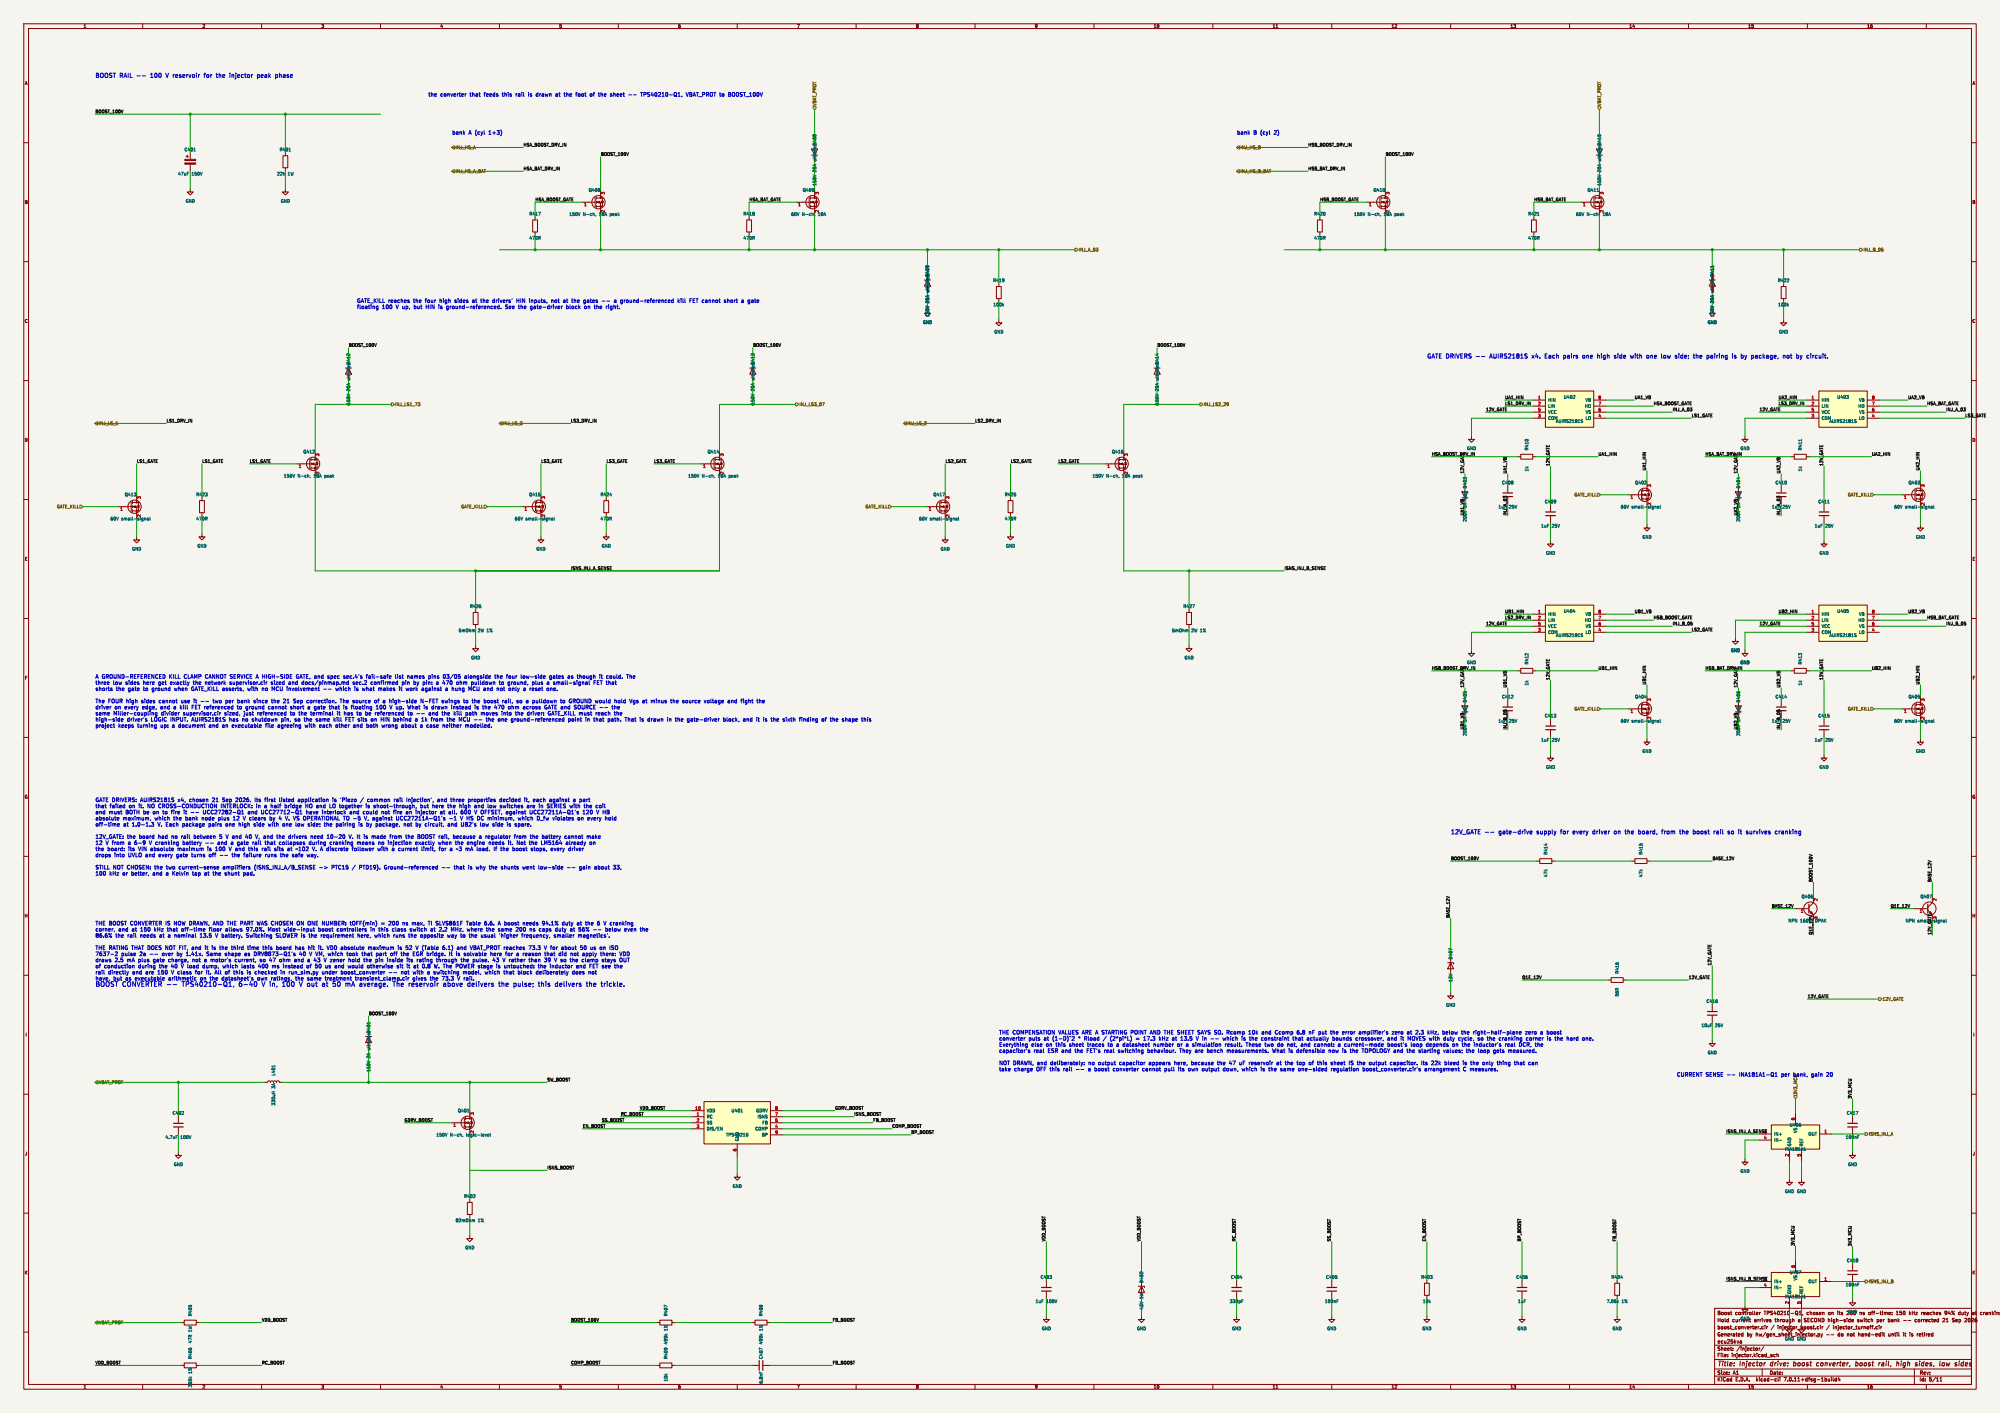
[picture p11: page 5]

2 3Q410 R420 150V N-ch, 18A peak 470R GND D410 150V 20A ultrafast 1
HSB_BOOST_DRV_IN

GNDGND D411 150V 20A ultrafast GND D409 150V 20A ultrafast GND

2 3 Q407 NPN small-signal GND

100 kHz or better, and a Kelvin tap at the shunt pad.

THE BOOST CONVERTER IS NOW DRAWN, AND THE PART WAS CHOSEN ON ONE NUMBER: tOFF(min) = 200 ns max, TI SLVS861F Table 6.6. A boost needs 94.1% duty at the 6 V cranking

draws 2.5 mA plus gate charge, not a motor's current, so 47 ohm and a 43 V zener hold the pin inside its rating through the pulse. 43 V rather than 39 V so the clamp stays OUT

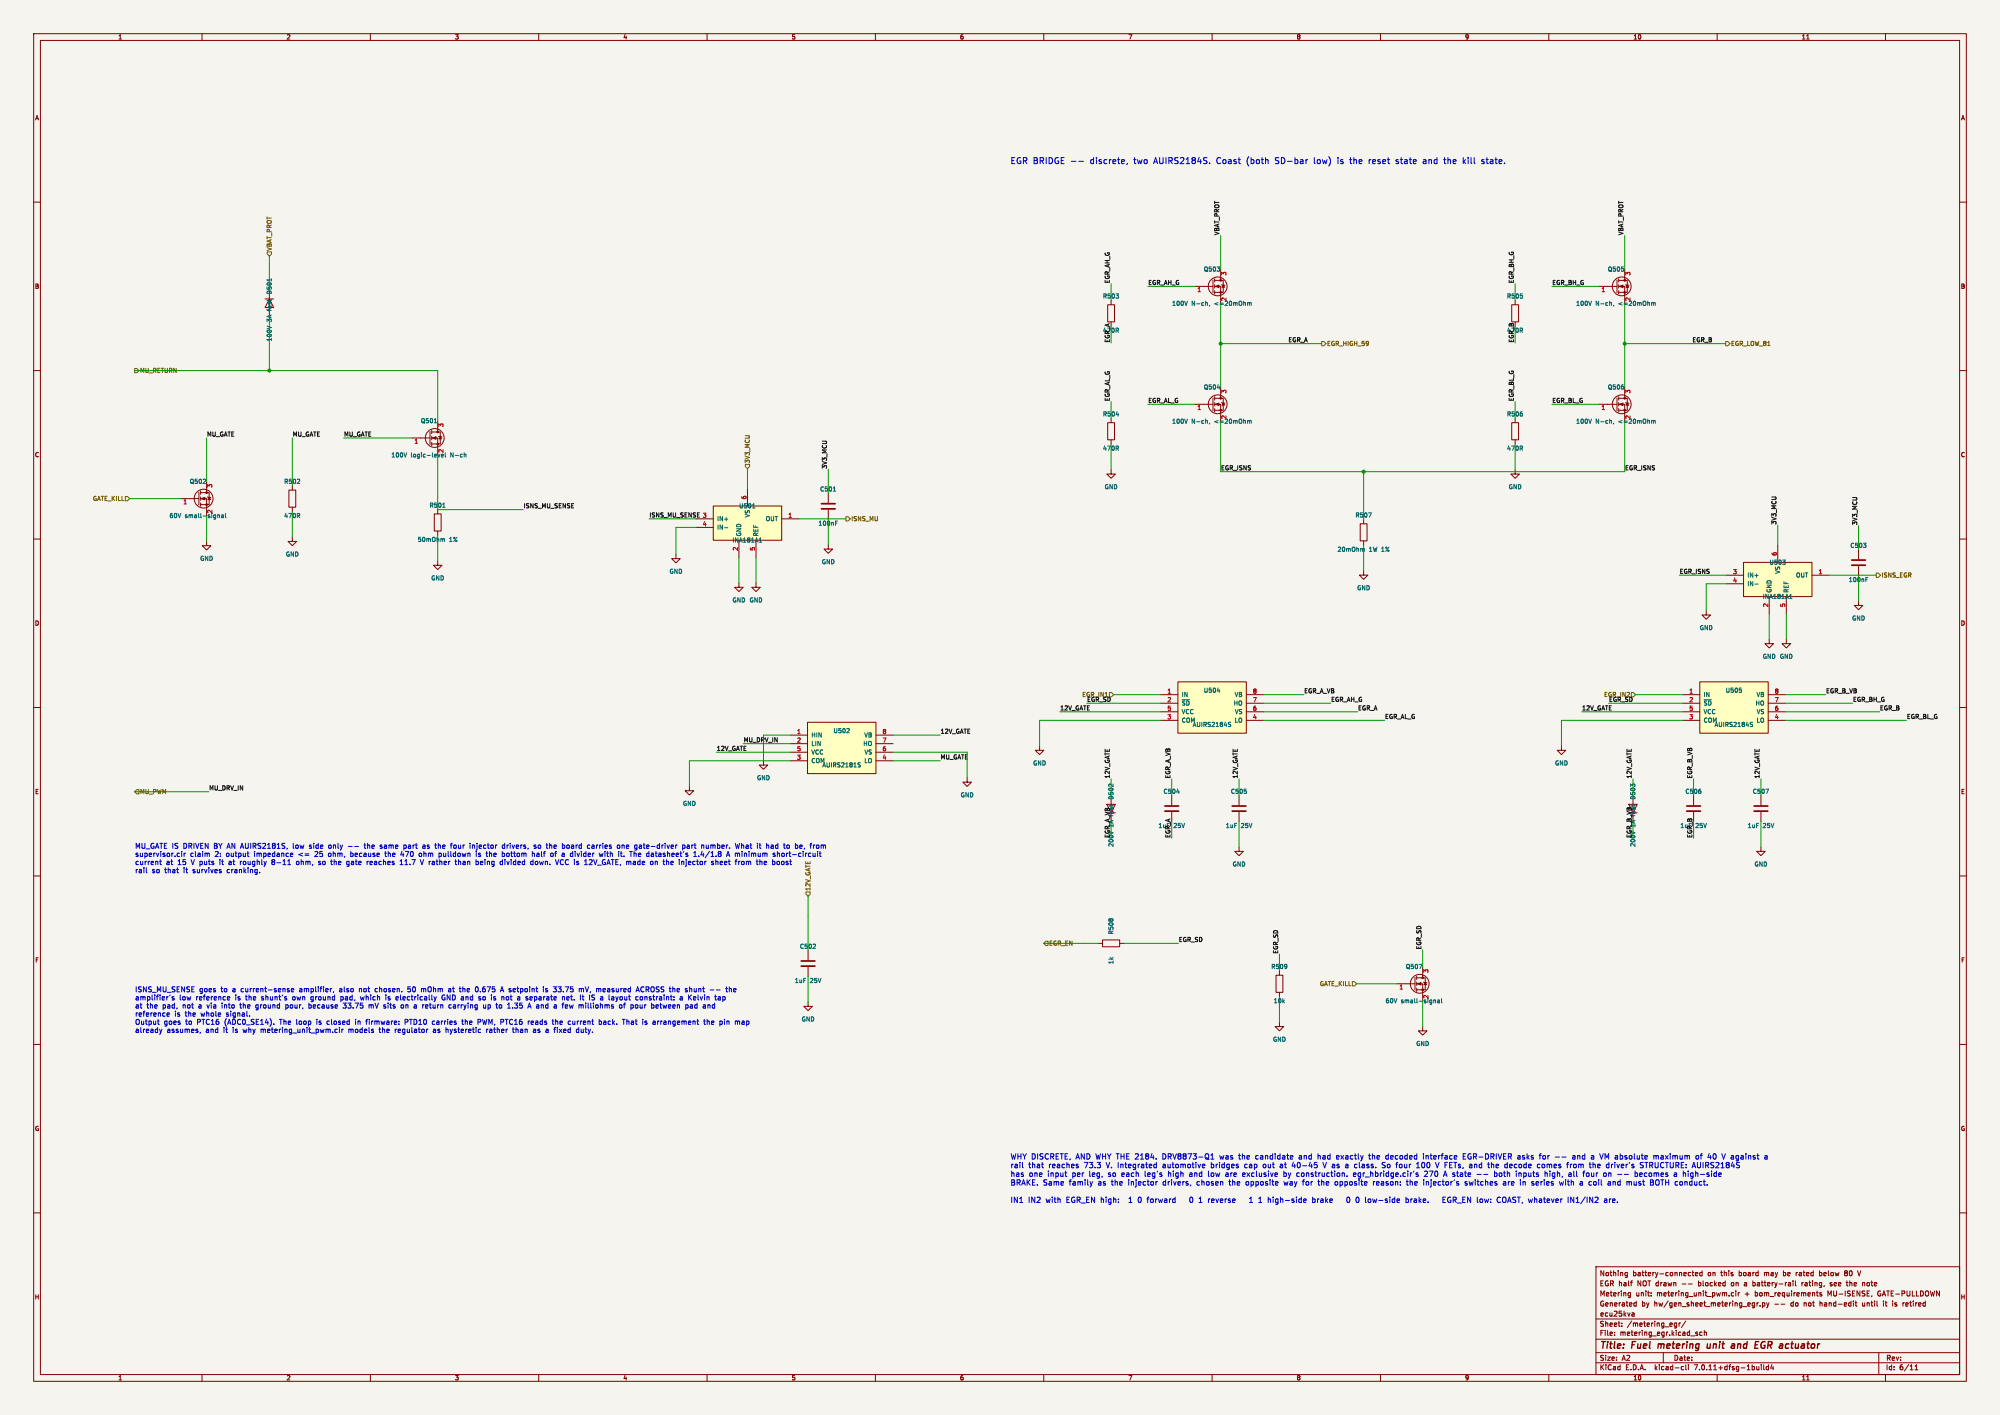
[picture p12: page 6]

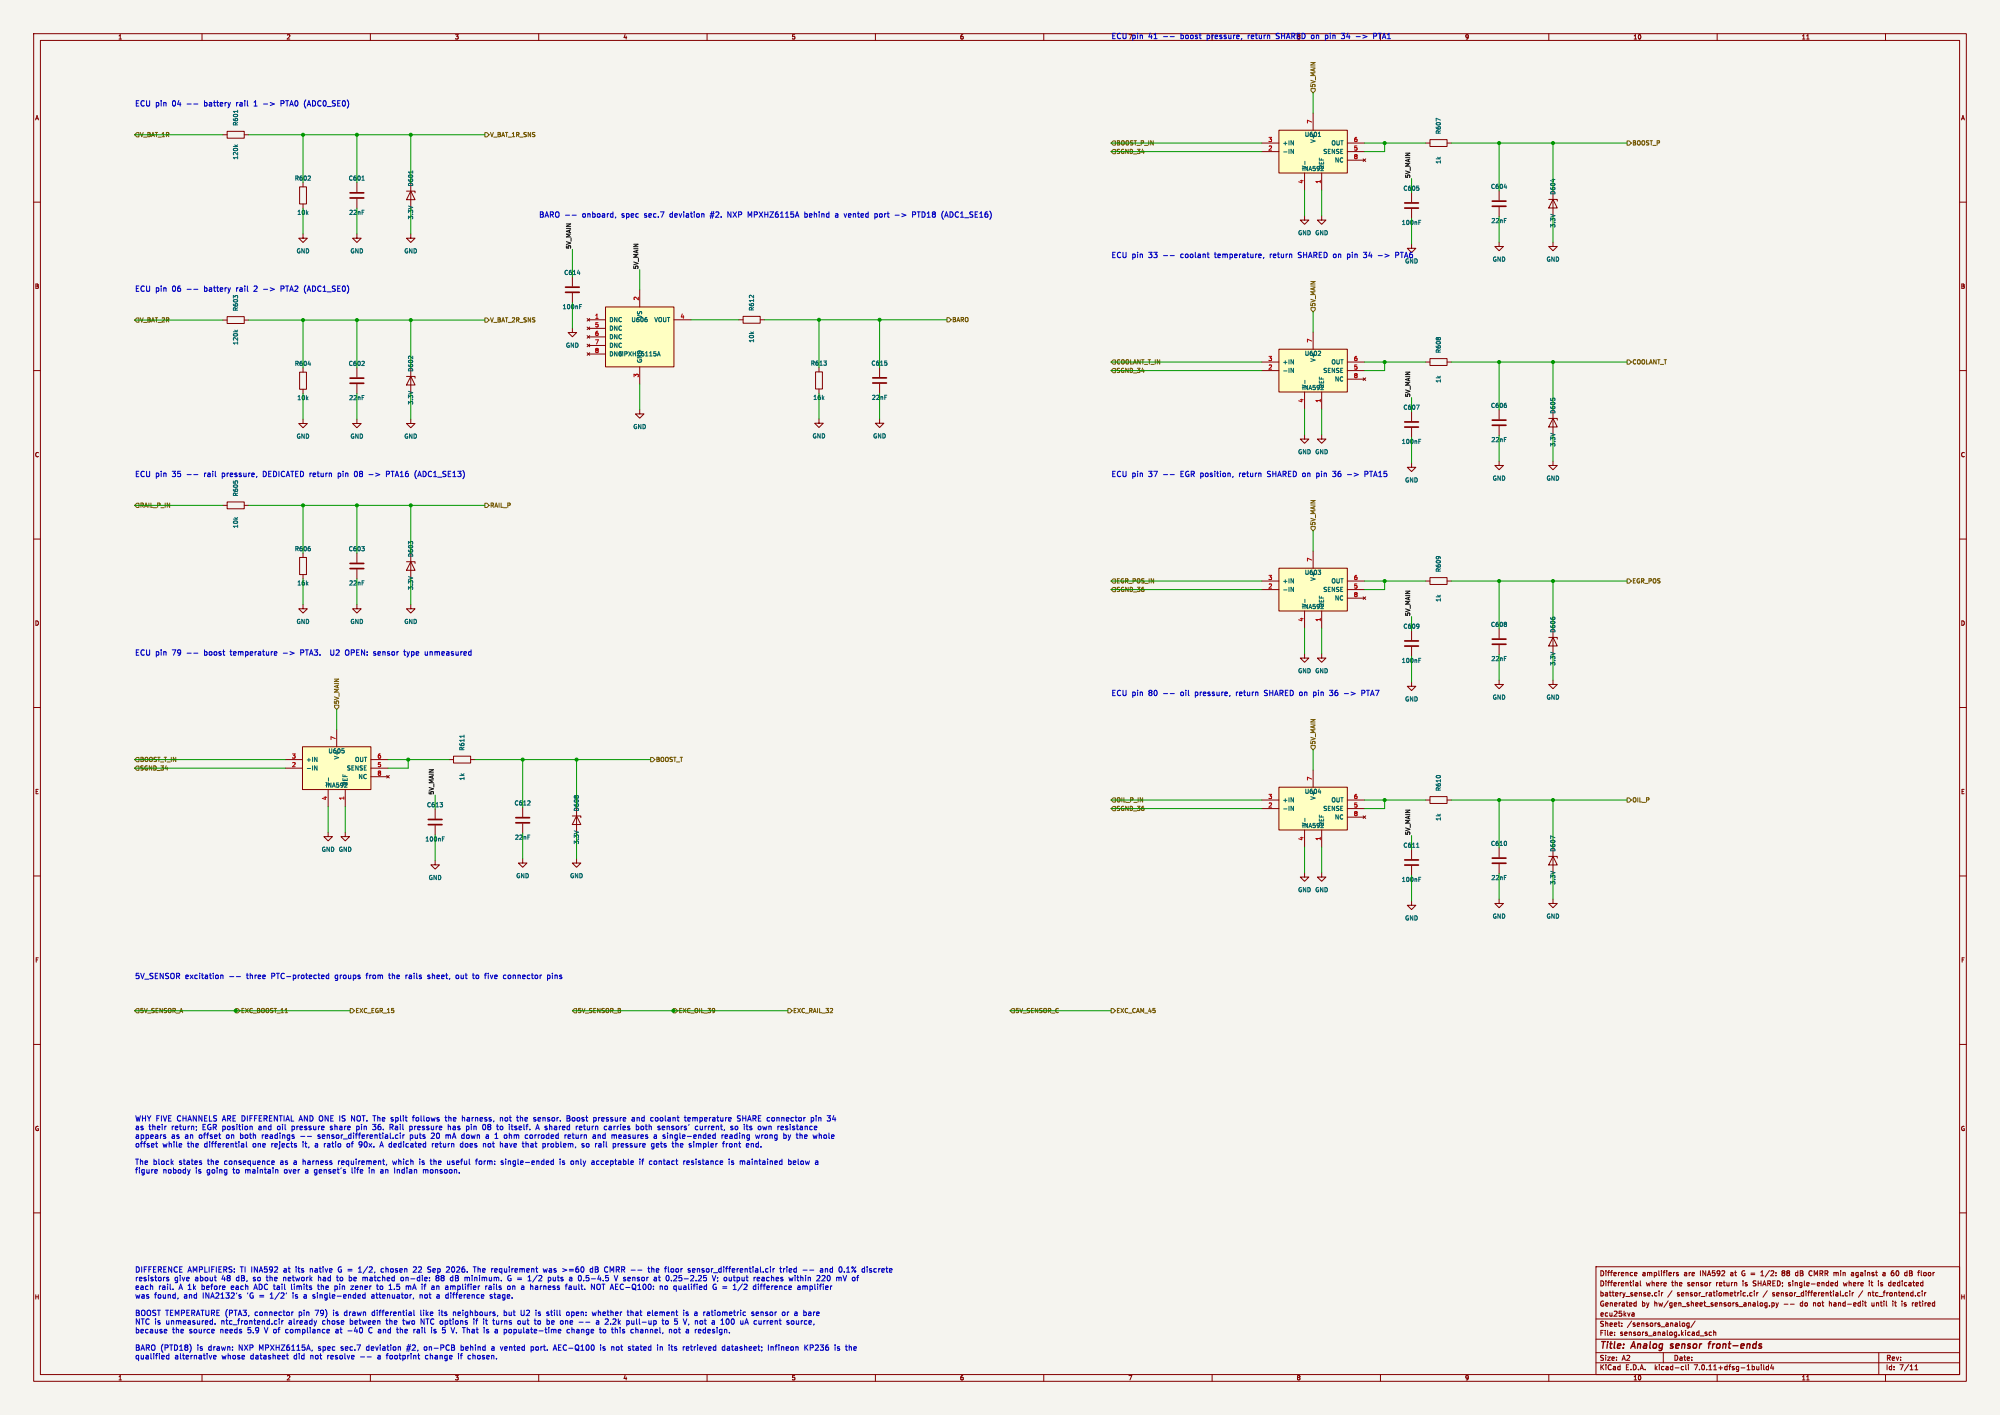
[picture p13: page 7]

3 VOUT 4 DNC 5 DNC 6 DNC 7 DNC 8 U606 MPXHZ6115A GND GND GND R608 1k

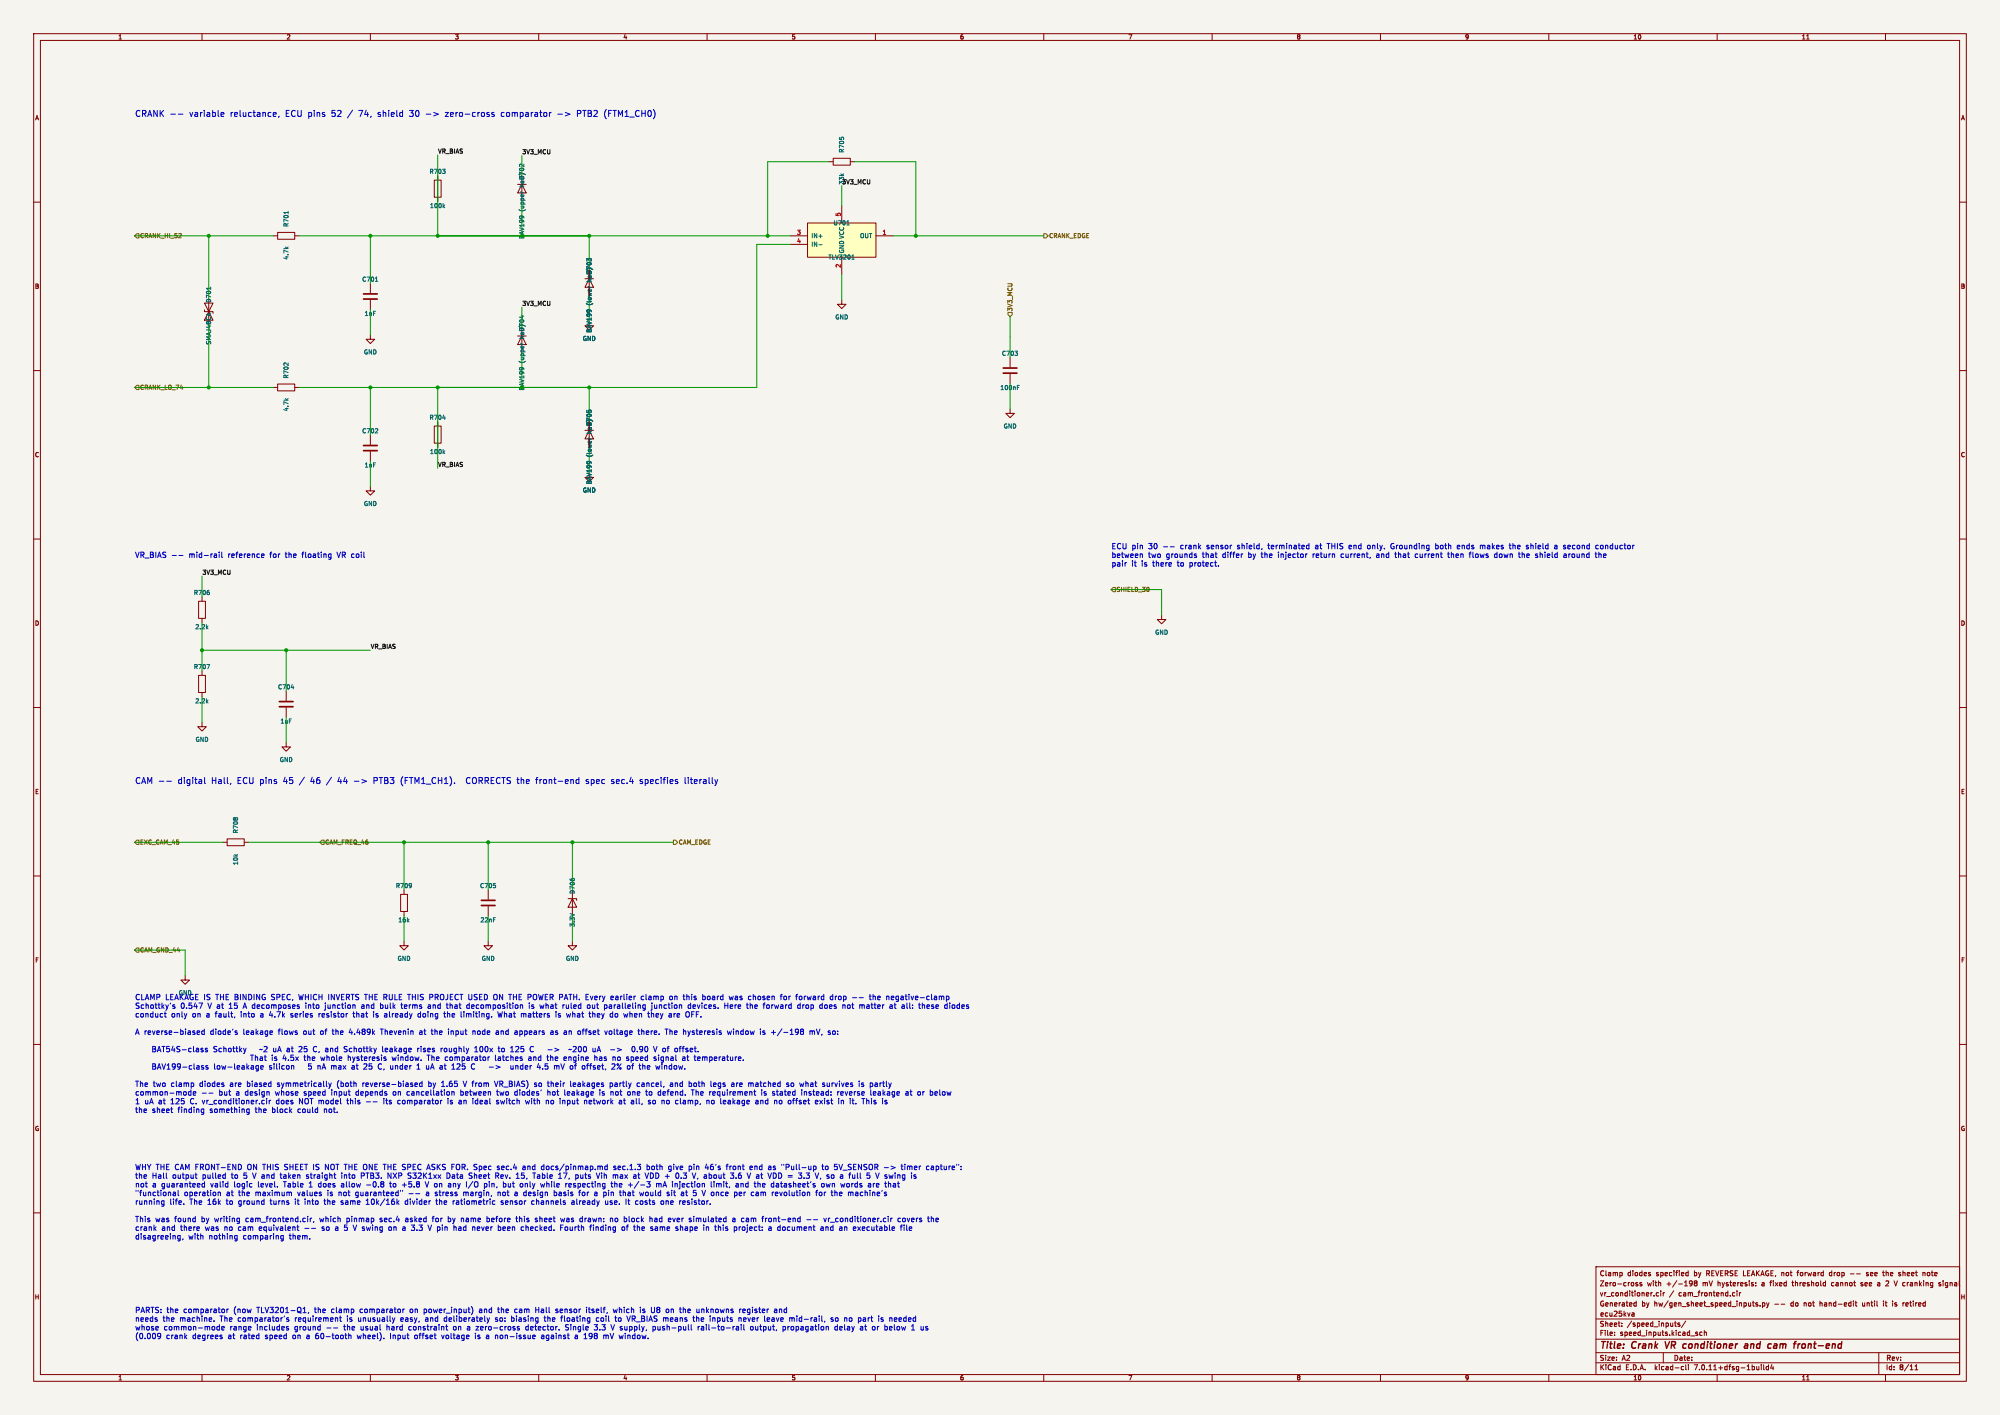
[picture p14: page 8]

pair it is there to protect.

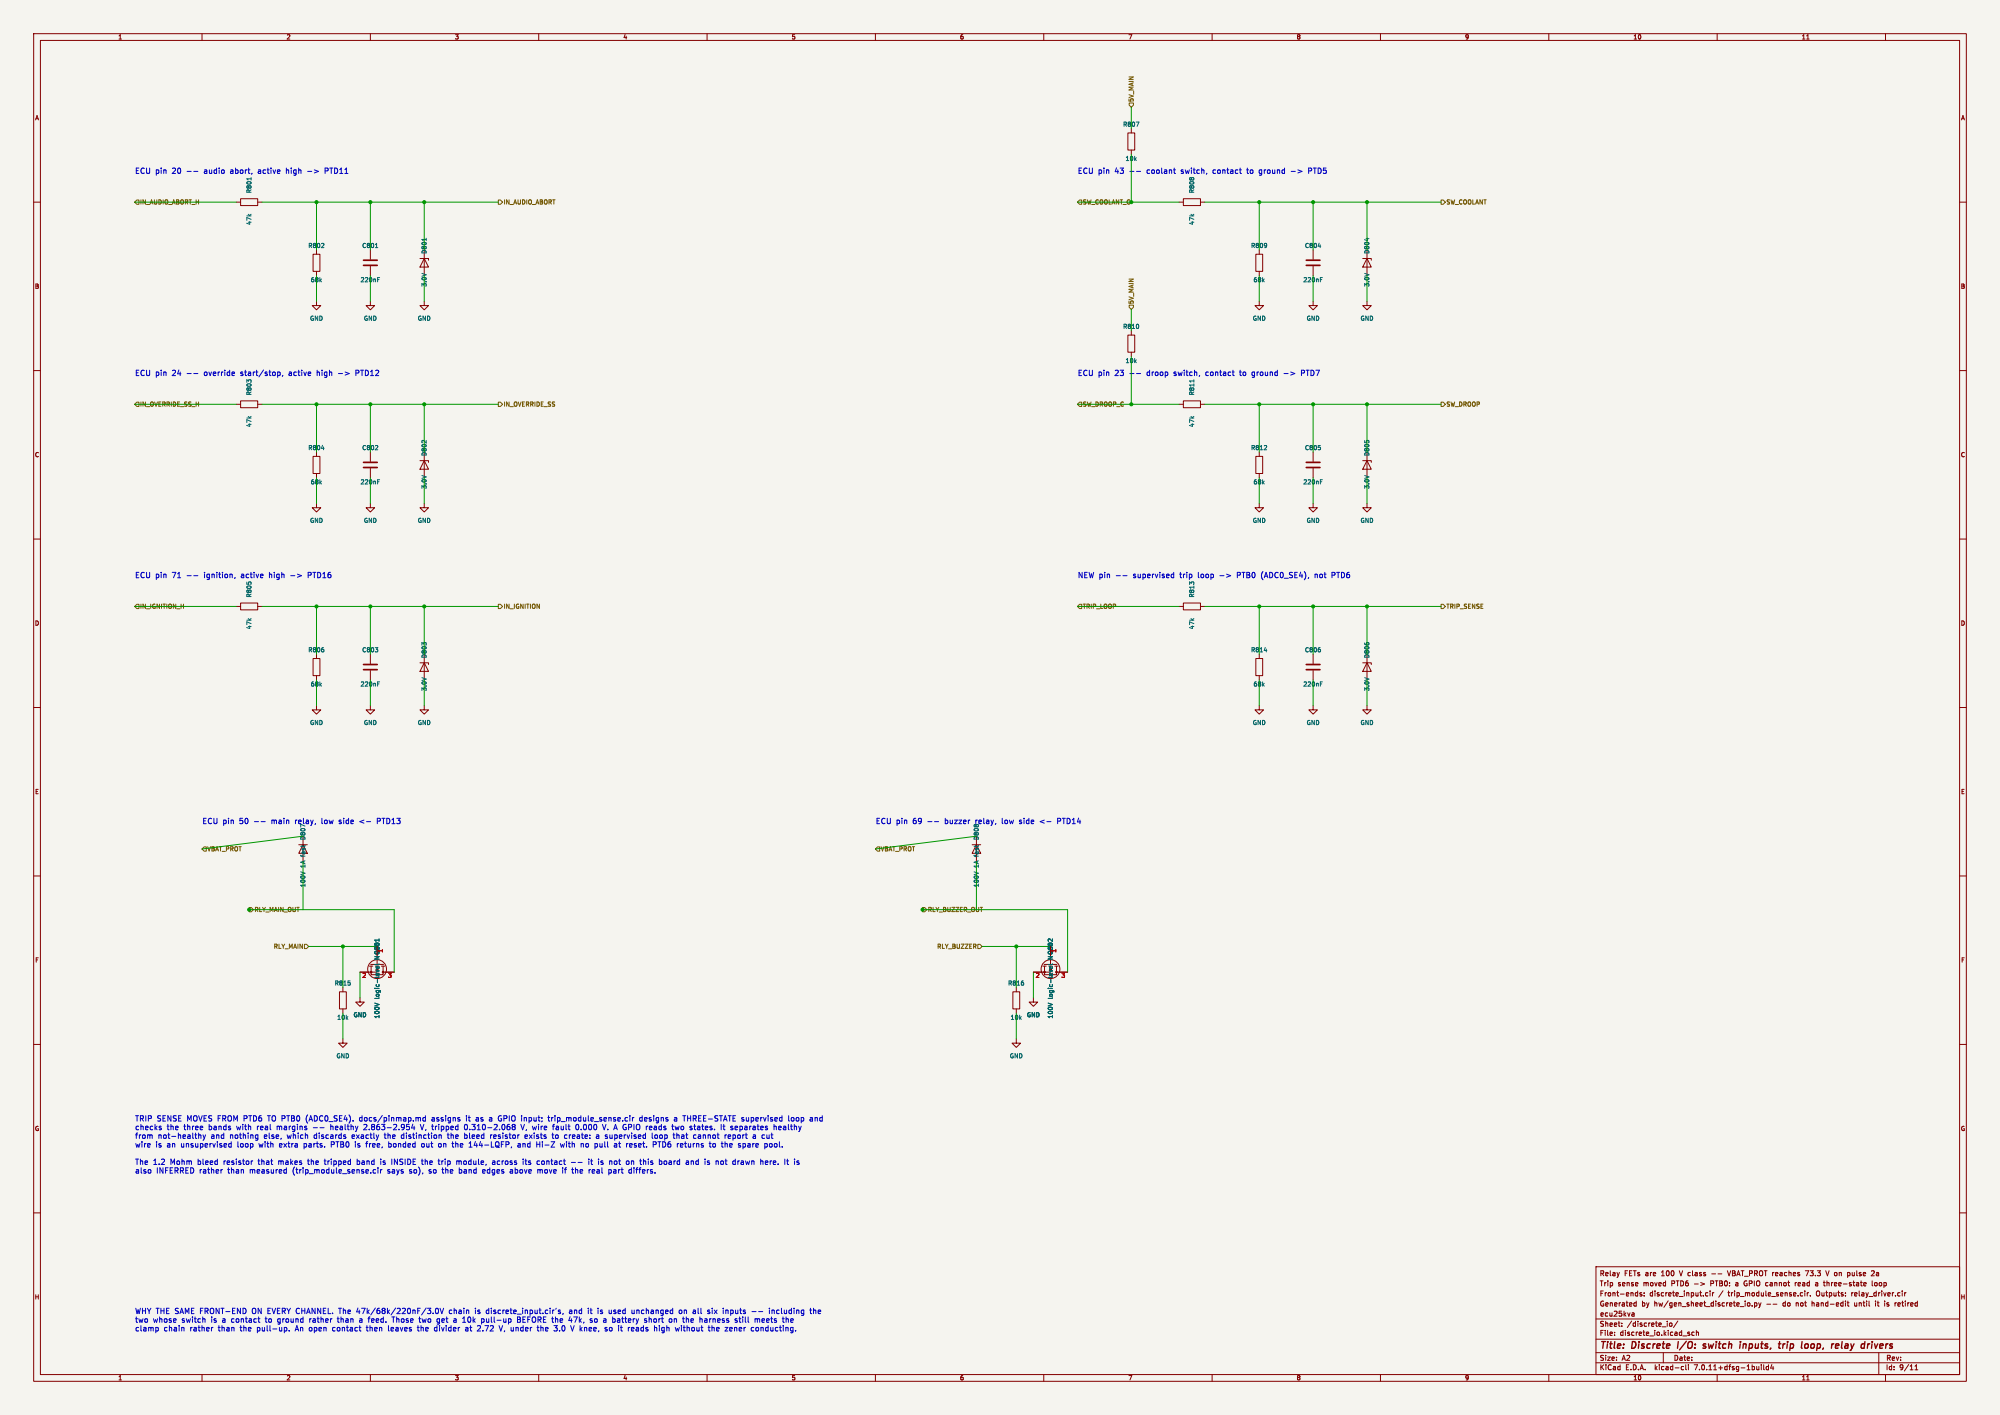
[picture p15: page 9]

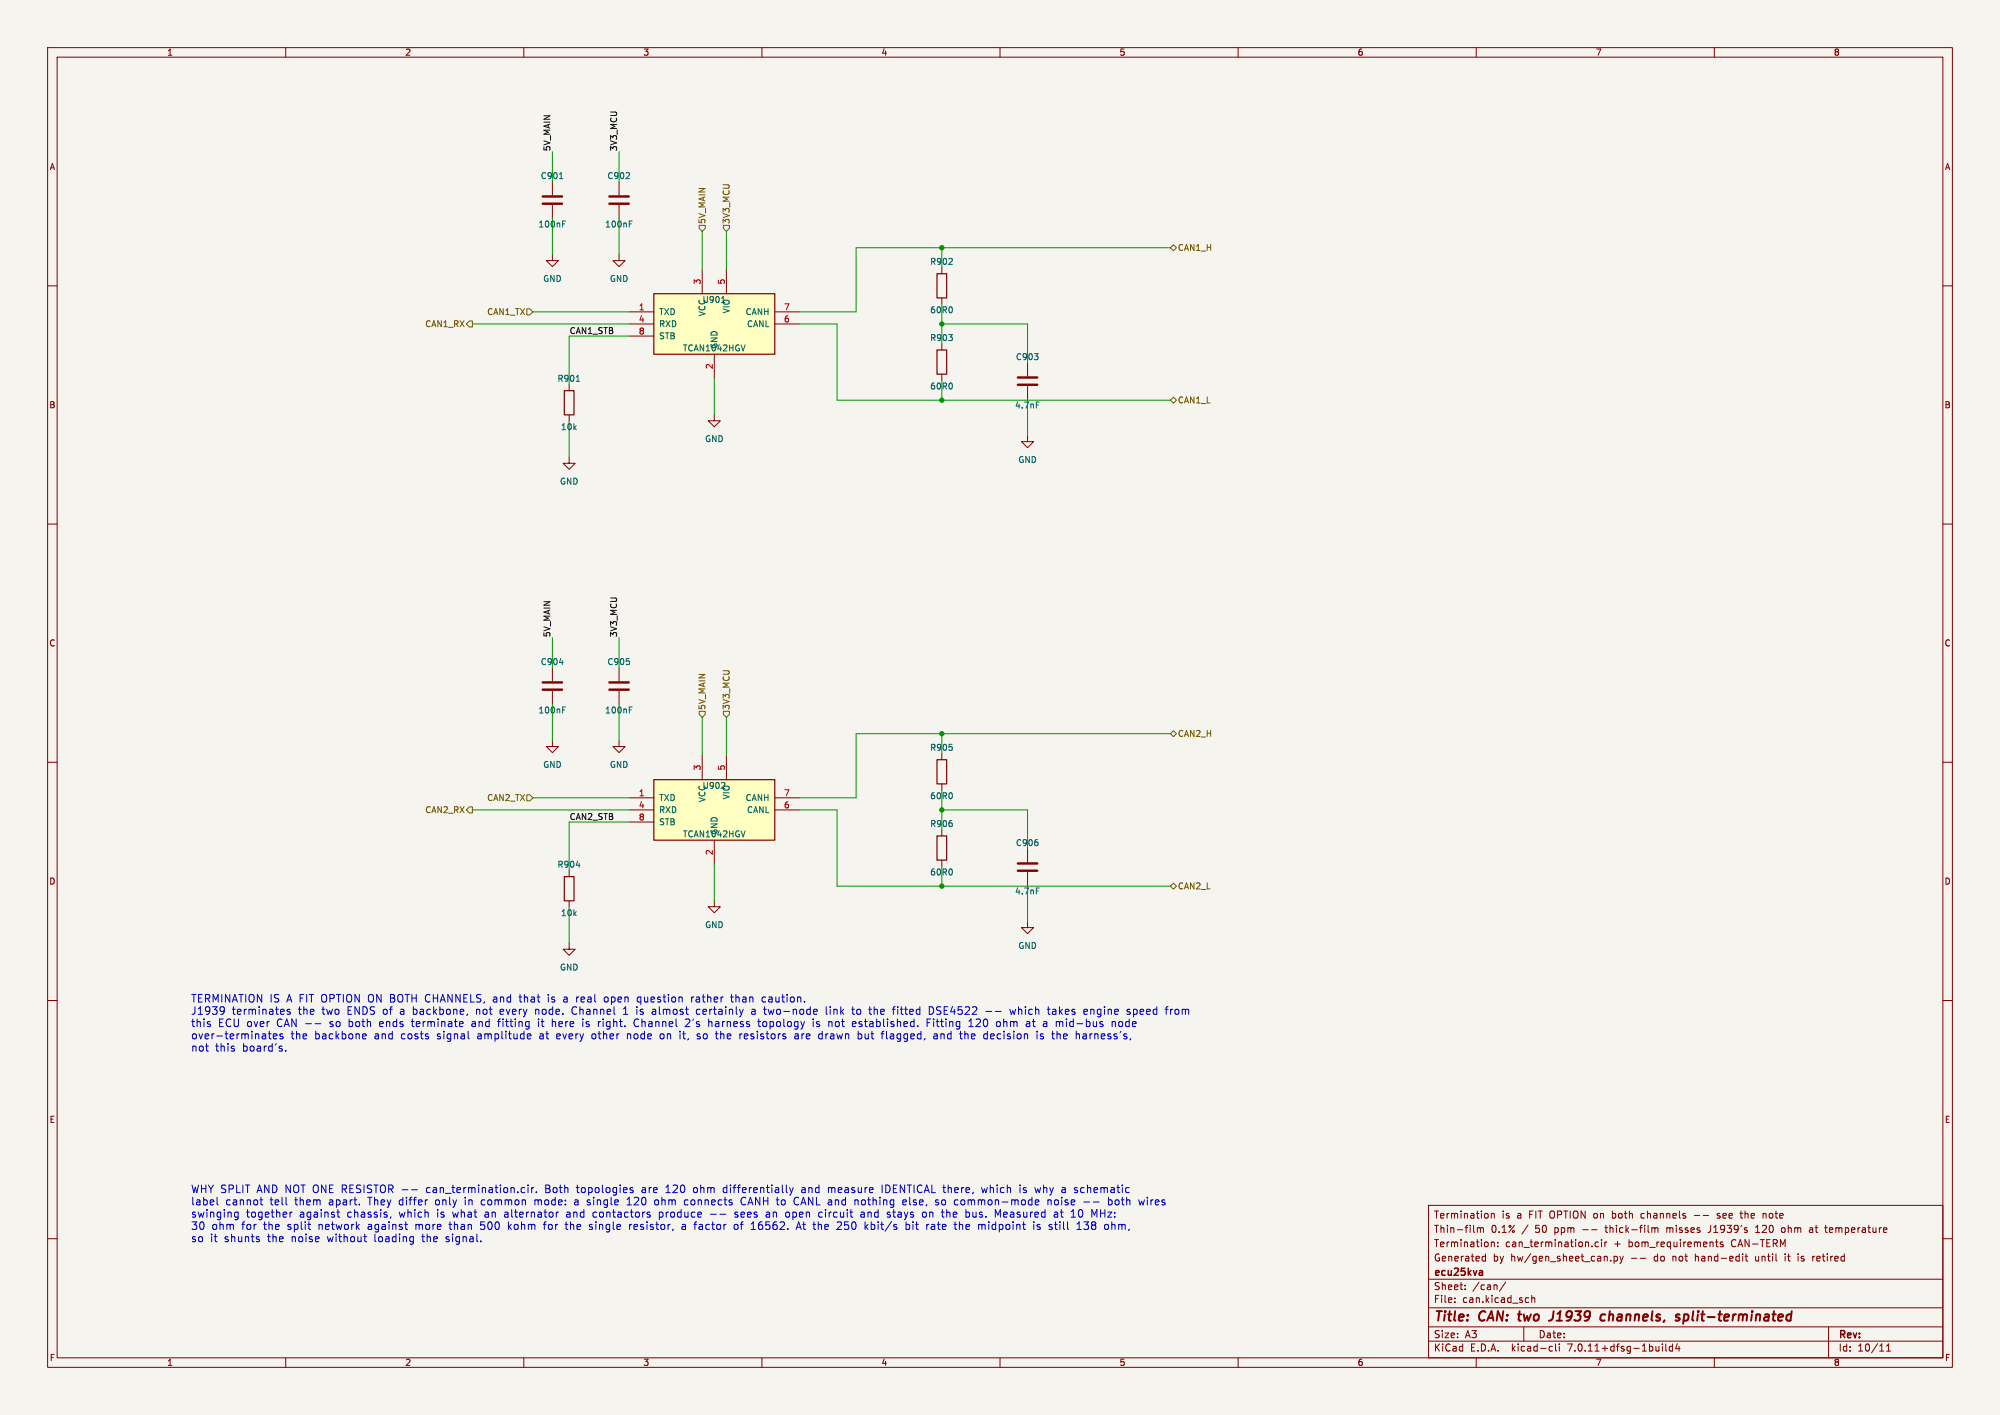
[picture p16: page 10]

TERMINATION IS A FIT OPTION ON BOTH CHANNELS, and that is a real open question rather than caution.

Id: 10/11 Title: CAN: two J1939 channels, split-terminated

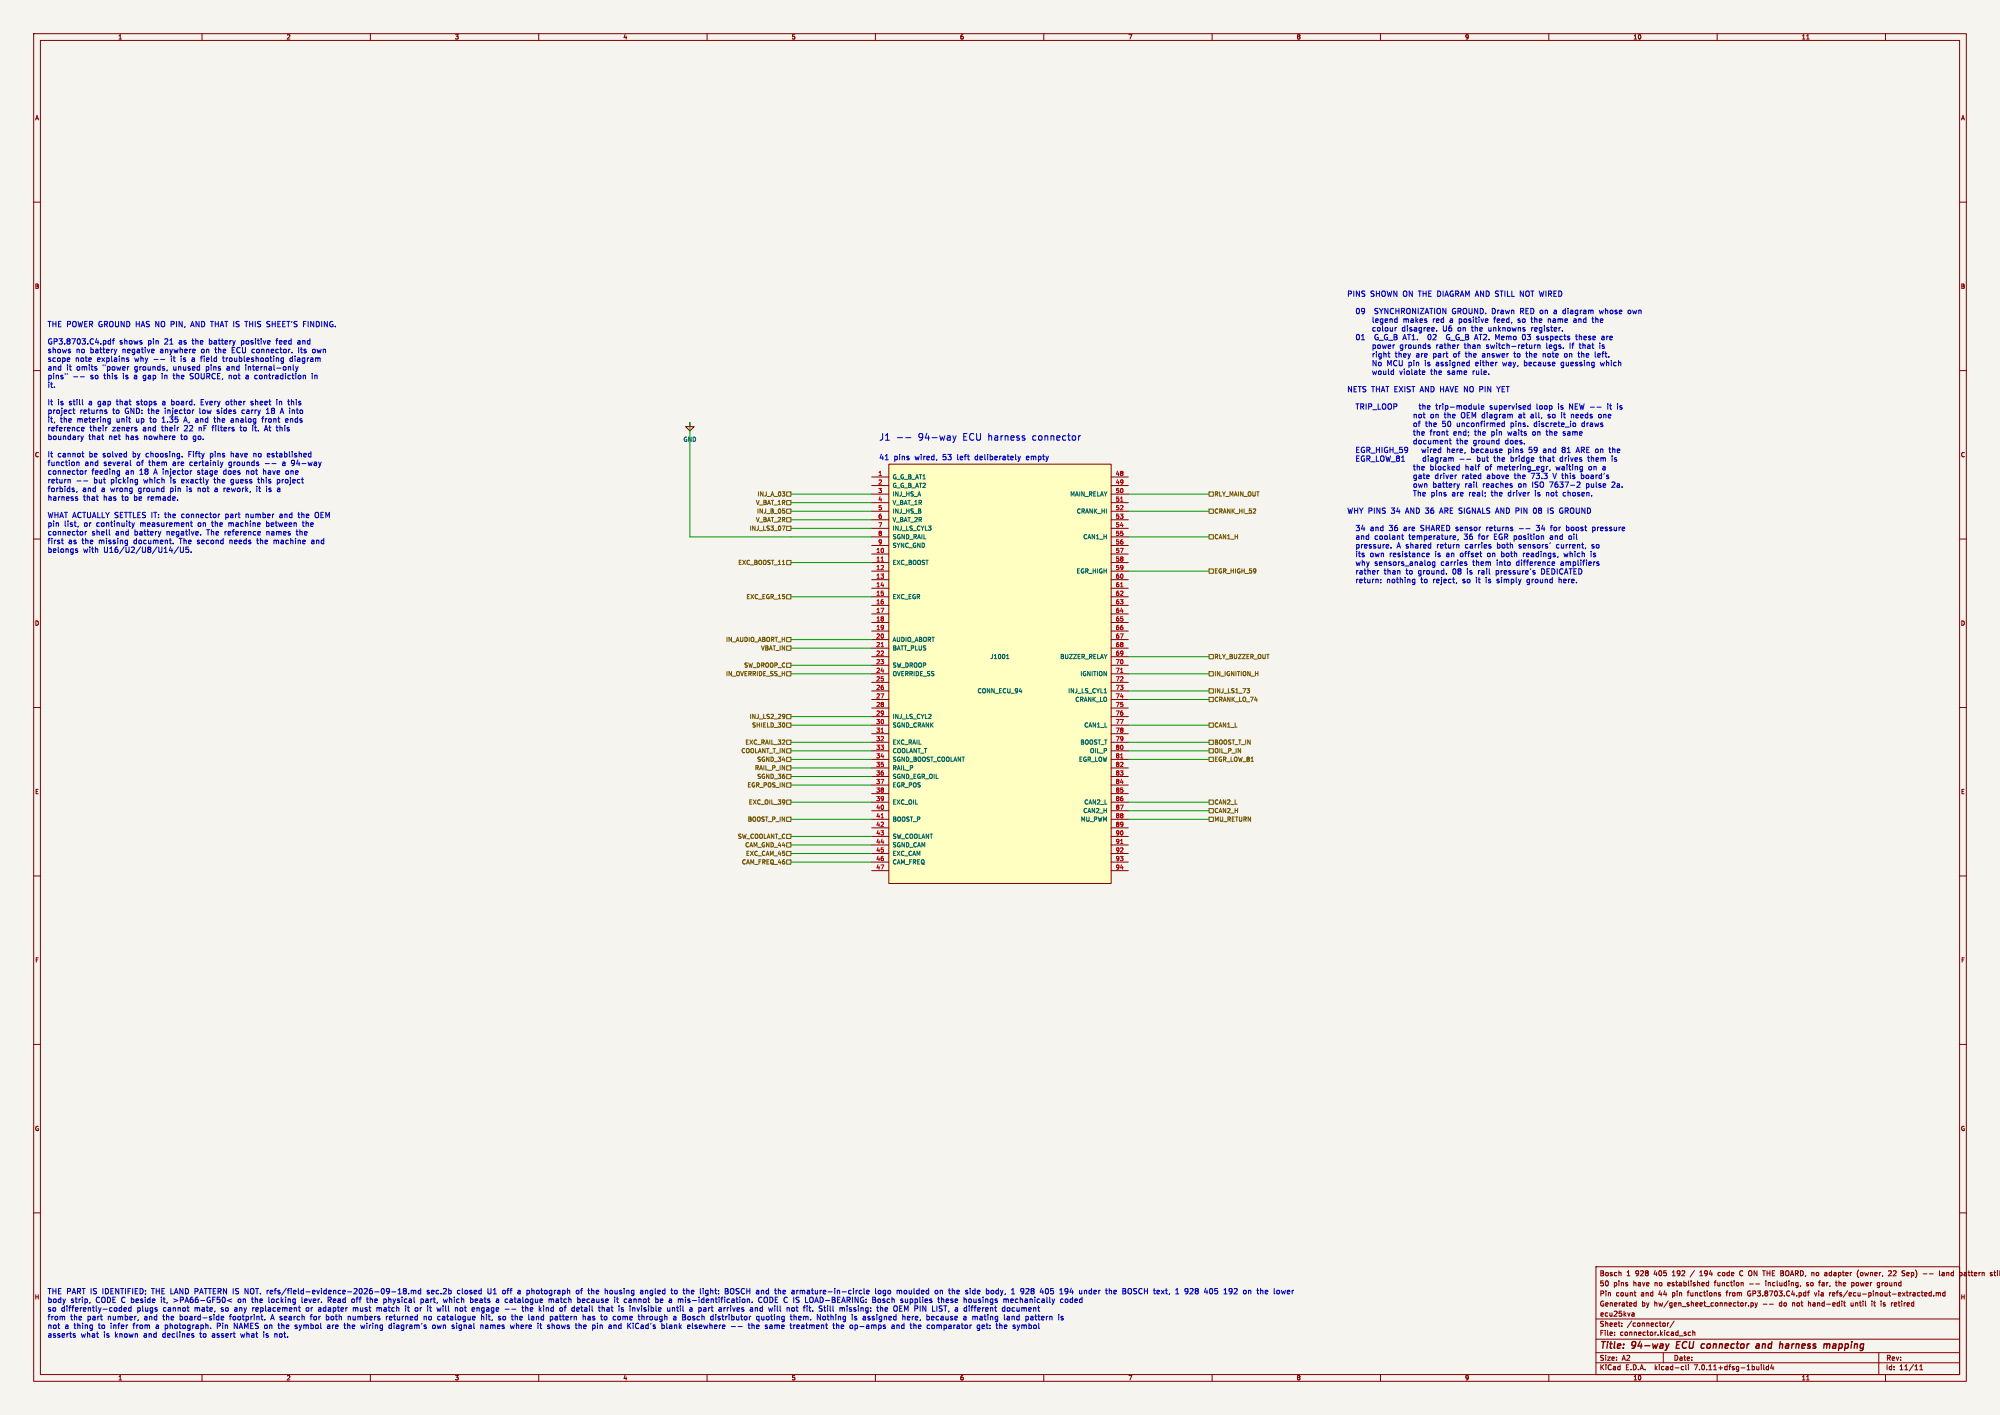
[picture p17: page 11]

PINS SHOWN ON THE DIAGRAM AND STILL NOT WIRED

legend makes red a positive feed, so the name and the
colour disagree. U6 on the unknowns register.
right they are part of the answer to the note on the left.
No MCU pin is assigned either way, because guessing which
would violate the same rule.

THE POWER GROUND HAS NO PIN, AND THAT IS THIS SHEET'S FINDING.

and it omits "power grounds, unused pins and internal-only

NETS THAT EXIST AND HAVE NO PIN YET

It is still a gap that stops a board. Every other sheet in this
it, the metering unit up to 1.35 A, and the analog front ends
boundary that net has nowhere to go.

the front end; the pin waits on the same

forbids, and a wrong ground pin is not a rework, it is a
harness that has to be remade.

The pins are real; the driver is not chosen.

WHY PINS 34 AND 36 ARE SIGNALS AND PIN 08 IS GROUND

pressure. A shared return carries both sensors' current, so

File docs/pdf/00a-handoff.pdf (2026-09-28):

# Handoff—state ofthe

# project, 28September2026

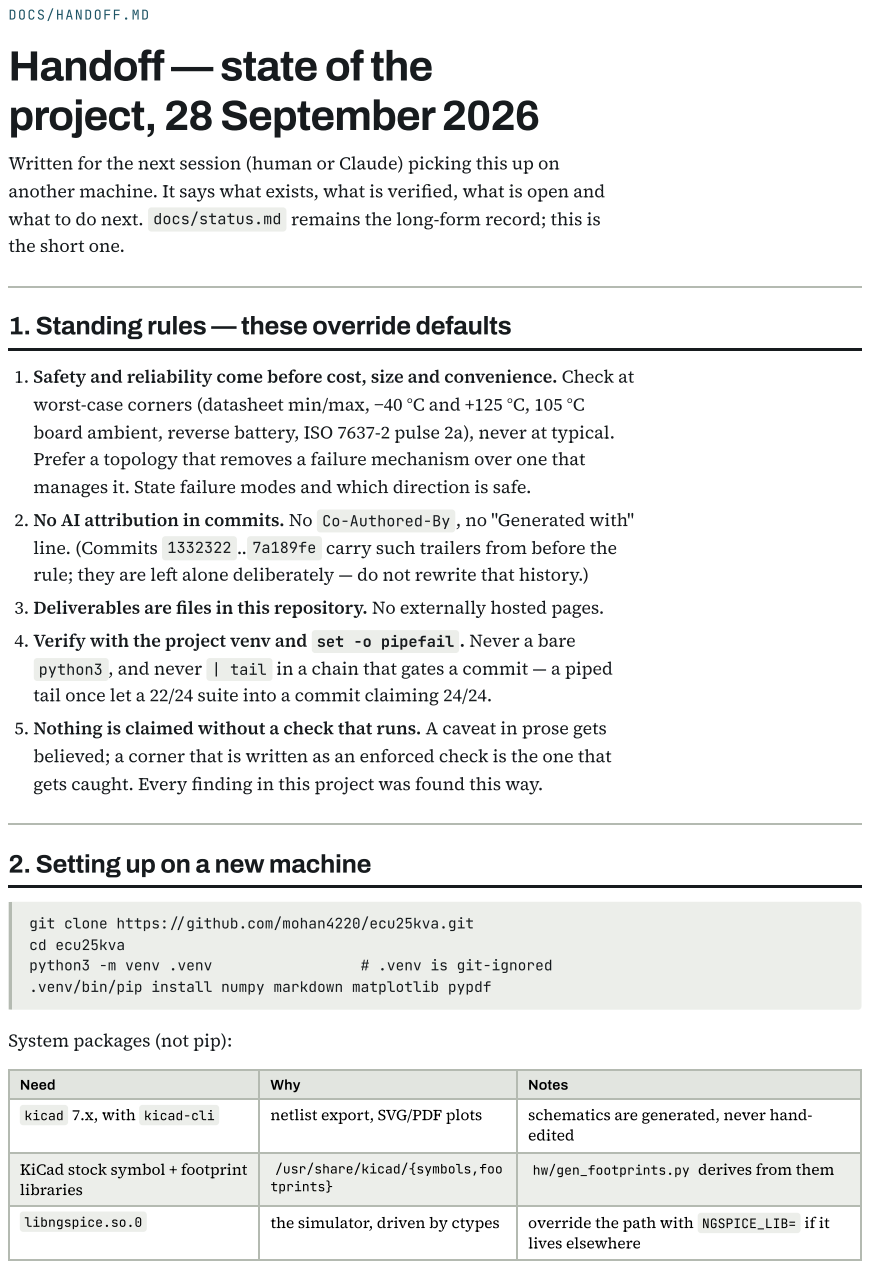
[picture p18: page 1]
python3 -m venv .venv; # .venv is git-ignored

DOCS/HANDOFF.MD

Written for the next session (human or Claude) picking this up on

another machine. It says what exists, what is verified, what is open and

what to do next. docs/status.md remains the long-form record; this is

the short one.

1. Standing rules — these override defaults

1. Safety and reliability come before cost, size and convenience. Check at

worst-case corners (datasheet min/max, −40 °C and +125 °C, 105 °C

board ambient, reverse battery, ISO 7637-2 pulse 2a), never at typical.

Prefer a topology that removes a failure mechanism over one that

manages it. State failure modes and which direction is safe.

2. No AI attribution in commits. No Co-Authored-By , no "Generated with"

line. (Commits 1332322 .. 7a189fe carry such trailers from before the

rule; they are left alone deliberately — do not rewrite that history.)

3. Deliverables are files in this repository. No externally hosted pages.

4. Verify with the project venv and set -o pipefail . Never a bare

python3 , and never | tail in a chain that gates a commit — a piped

tail once let a 22/24 suite into a commit claiming 24/24.

5. Nothing is claimed without a check that runs. A caveat in prose gets

believed; a corner that is written as an enforced check is the one that

gets caught. Every finding in this project was found this way.

2. Setting up on a new machine

git clone https: /github.com/mohan4220/ecu25kva.git

cd ecu25kva
.venv/bin/pip install numpy markdown matplotlib pypdf

System packages (not pip):

Need | Why | Notes

kicad 7.x, with kicad-cli | netlist export, SVG/PDF plots | schematics are generated, never hand-edited

KiCad stock symbol + footprint libraries | /usr/share/kicad/{symbols,foo tprints} | hw/gen_footprints.py derives from them

libngspice.so.0 | the simulator, driven by ctypes | override the path with NGSPICE_LIB= if it lives elsewhere

set -o pipefail; .venv/bin/python sim/run_sim.py | tail -3; # expect 24/24 blocks pass; .venv/bin/python hw/check_netlist.py | tail -6; # expect "schematic connectivity OK", 2 open it; .venv/bin/python hw/assign_passives.py; # expect 202 packaged, 0 unresolved; .venv/bin/python docs/build_pdf.py | tail -1; # rebuilds docs/pdf/ECU-Bible.pdf; firmware exists.

Need | Why | Notes

inkscape , imagemagick | only for eyeballing rendered sheets | optional

Verify the whole project in one go:

The schematics are generated. Edit hw/gen_sheet_*.py , then

.venv/bin/python hw/gen_sheet_<name>.py -force . Without -force

the generator refuses to overwrite a non-empty file. After adding or re-

valuing any R or C, re-run assign_passives.py and then regenerate the

sheets again so the footprints land.

3. Where things stand

Phase 2 (schematic capture) is complete and checked. Ten hierarchical

sheets, root wired, project netlist verified. Phase 3 (part selection) is

most of the way through; phase 4 (PCB) has not started, and no

Gate | State

Simulation blocks | 24 of 24 pass

Netlist connectivity | passes, with 2 named open items

Footprints | 300 of 319 components

Chip R and C packaged | 202 of 202

Verified part numbers are in docs/bom_requirements.md under

"Chosen parts" — every one against a datasheet that was actually

retrieved and read. That now covers the MCU, regulators, supervisor,

gate drivers, current-sense and difference amplifiers, comparator, the

boost controller, all sixteen power FETs, the small-signal FETs, 27

diodes, the gate-rail transistors, the buck inductor, and the packaging

of every chip resistor and capacitor.

Design decisions taken with the owner are in docs/decisions-log.md

— the four approved findings, the discrete-input redesign and the

sensor-supply redesign, with the options and reasoning for each.

## 4. What is open, in the orderI would do it

### 4.1 Three approved redesigns, not yet built

1. POWER-PATH — move the injector and EGR supply onto connector pins

04/06 (10 A fused each in the loom) with their own protection, leaving

pin 21 feeding the electronics through the EMI filter and reverse FET.

Today every high-current load runs through a path whose reverse FET

was sized for 5 A and whose filter never stated a DC current. Blocks:

L101, L102, F101. See docs/bom_requirements.md § POWER-PATH.
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

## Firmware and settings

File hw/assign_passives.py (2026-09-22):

#!/usr/bin/env python3
"""Package every resistor and capacitor from the voltage ACROSS it.

The package of a chip passive is not a free choice. A resistor has a
working-voltage ceiling and a power rating that falls with temperature;
a ceramic capacitor has a rated voltage and loses capacitance under DC
bias. On this board a node can reach 73.3 V (ISO 7637-2 pulse 2a) or
104 V (the injector boost rail), and an 0603 resistor is rated 75 V.
So the rule is computed, not remembered:

  1. every net gets (continuous max, peak max) volts, in NET_V below;
  2. a part's voltage is the worst difference between its two nets --
     except inside a FLOATING domain (a bootstrap supply riding on an
     injector bank node), where it is the domain's own swing;
  3. a resistor's power is V_cont^2 / R -- CONTINUOUS, because a 50 us
     pulse does not set a wattage -- unless the value states its own
     wattage, or the net pair is in PAIR_V with what is really across it;
  4. the smallest package that clears both, at a 105 C board
     (ASSUMED -- the spec states no ambient), wins.

Resistor ratings: Vishay D/CRCW e3 (AEC-Q200), standard operation mode,
retrieved 22 Sep 2026. Power derates linearly from 70 C to 0 at 155 C,
which is x0.588 at 105 C. Voltage margin: the rail table's 1.09x.

Capacitors: rated voltage must clear the peak and 1.5x the continuous
voltage (DC-bias headroom); the package is looked up in CAP_PACKAGE,
which lists only (value, rating) pairs checked against a manufacturer
part. A pair not in that table stops the script rather than guessing.

Writes lib/passive_fp.json: ref -> (footprint, why). schlib.place()
applies it; check_netlist.py fails if it goes stale.
"""
import collections
import json
import os
import re
import subprocess
import sys
import tempfile

HW = os.path.dirname(os.path.abspath(__file__))
OUT = os.path.join(HW, "lib", "passive_fp.json")

T_BOARD = 105.0
DERATE = (155.0 - T_BOARD) / (155.0 - 70.0)
V_MARGIN = 1.09

# size: (P70 W, Umax V) -- Vishay D/CRCW e3, standard mode
R_SIZES = [("0402", 0.063, 50.0), ("0603", 0.10, 75.0),
           ("0805", 0.125, 150.0), ("1206", 0.25, 200.0),
           ("1210", 0.5, 200.0), ("2010", 0.75, 400.0),
           ("2512", 1.0, 500.0)]
R_MIN_SIZE = "0603"          # nothing smaller: hand rework, probe access

BAT = (24.0, 73.3)           # jump-start continuous, pulse 2a peak
HARNESS = (24.0, 73.3)       # any loom wire can be shorted to battery
BOOST = (104.0, 104.0)
LOGIC3 = (3.6, 3.6)
LOGIC5 = (5.5, 5.5)
GATE12 = (13.6, 13.6)        # 12V_GATE high corner, run_sim

NET_V = {
    "GND": (0.0, 0.0),
    # battery side
    "/VBAT_PROT": BAT, "/power_input/VBAT_CLAMPED": BAT,
    "/power_input/VBAT_REV_GATE": BAT, "/V_BAT_1R": HARNESS,
    "/V_BAT_2R": HARNESS, "/TRIP_LOOP": HARNESS,
    "/IN_AUDIO_ABORT_H": HARNESS, "/IN_OVERRIDE_SS_H": HARNESS,
    "/IN_IGNITION_H": HARNESS, "/SW_COOLANT_C": HARNESS,
    "/SW_DROOP_C": HARNESS, "/EGR_HIGH_59": BAT, "/EGR_LOW_81": BAT,
    "/RAIL_P_IN": HARNESS, "/CAM_FREQ_46": HARNESS,
    "/rails/SW": BAT,
    "/power_input/VBAT_EMI1": BAT,    # between L1 and the ferrite
    "Net-(U201-EN{slash}UVLO)": (6.0, 18.3),   # 24.9k/(75k+24.9k) of rail
    "/power_input/NCL_SENSE": (5.7, 5.7),      # BAV199 to 5V_MAIN
    "/power_input/NCL_REF": LOGIC5, "/power_input/NCL_OUT": LOGIC5,
    "/power_input/EMI_DAMP": (0.1, 1.0),  # Cd/Rd node: ripple only
    # injector boost
    "/injector/BOOST_100V": BOOST,
    # bank nodes: boost only for the 38 us peak; battery through hold
    "/INJ_A_03": (24.0, 104.0), "/INJ_B_05": (24.0, 104.0),
    "/injector/FB_BOOST_MID": (51.0, 51.0),  # 499k/499k midpoint
    "/injector/BIAS_12V_MID": (58.5, 58.5),  # 47k/47k midpoint
    "/injector/Q1C_MID": (83.5, 83.5),  # collector string midpoint
    "/injector/Q1C_12V": (67.0, 67.0),
    "/injector/BASE_12V": (13.7, 13.7), "/injector/Q1E_12V": GATE12,
    "/injector/VDD_BOOST": (24.0, 46.6), "/injector/RC_BOOST": (24.0, 46.6),
    "/injector/BP_BOOST": (8.5, 8.5), "/injector/EN_BOOST": LOGIC5,
    "/injector/FB_BOOST": LOGIC5, "/injector/COMP_BOOST": LOGIC5,
    "/injector/SS_BOOST": LOGIC5, "/injector/COMP_RC_BOOST": LOGIC5,
    "/injector/ISNS_BOOST": (0.3, 0.3),
    "/injector/ISNS_INJ_A_SENSE": (0.3, 0.3),
    "/injector/ISNS_INJ_B_SENSE": (0.3, 0.3),
    # gate drive
    "/12V_GATE": GATE12, "/GATE_KILL": (13.7, 13.7),
    "/injector/LS1_GATE": GATE12, "/injector/LS2_GATE": GATE12,
    "/injector/LS3_GATE": GATE12, "/metering_egr/MU_GATE": GATE12,
    "/metering_egr/EGR_AL_G": GATE12, "/metering_egr/EGR_BL_G": GATE12,
    # floating: absolute values are the bank's, but see DOMAINS
    "/injector/UA1_VB": BOOST, "/injector/UA2_VB": BOOST,
    "/injector/UB1_VB": BOOST, "/injector/UB2_VB": BOOST,
    "/injector/HSA_BOOST_GATE": BOOST, "/injector/HSA_BAT_GATE": BOOST,
    "/injector/HSB_BOOST_GATE": BOOST, "/injector/HSB_BAT_GATE": BOOST,
    "/metering_egr/EGR_A_VB": BAT, "/metering_egr/EGR_B_VB": BAT,
    "/metering_egr/EGR_AH_G": BAT, "/metering_egr/EGR_BH_G": BAT,
    # sense and logic
    "/metering_egr/EGR_ISNS": (0.3, 0.3),
    "/metering_egr/ISNS_MU_SENSE": (0.3, 0.3),
    "/3V3_MCU": LOGIC3, "/5V_MAIN": LOGIC5, "/5V_SENSOR_C": LOGIC5,
    "/SENSOR_5V_MON": LOGIC5, "/rails/PGOOD_5V": LOGIC5,
    "/rails/FB_5V": LOGIC5, "/rails/BST": BAT,
    "Net-(U201-RON)": LOGIC5,
    "/V_BAT_1R_SNS": (5.7, 5.7), "/V_BAT_2R_SNS": (5.7, 5.7),
    # VR pair: ~14 V rms at rated speed, 48 V at the TVS standoff
    "/CRANK_HI_52": (14.0, 48.0), "/CRANK_LO_74": (14.0, 48.0),
    "/speed_inputs/VR_HI_CLAMPED": (3.9, 3.9),
    "/speed_inputs/VR_LO_CLAMPED": (3.9, 3.9),
    "/speed_inputs/VR_BIAS": LOGIC3,
    # CAN: normal bus is a few volts; the rating covers a battery short
    "/CAN1_H": (3.0, 40.0), "/CAN1_L": (3.0, 40.0),
    "/CAN2_H": (3.0, 40.0), "/CAN2_L": (3.0, 40.0),
    "/can/CAN1_SPLIT": (3.0, 40.0), "/can/CAN2_SPLIT": (3.0, 40.0),
    "/discrete_io/RLY_MAIN_G": LOGIC5, "/discrete_io/RLY_BUZZER_G": LOGIC5,
}
# Nets at MCU logic level, by name pattern.
LOGIC3_RE = re.compile(
    r"^/(IN_AUDIO_ABORT|IN_OVERRIDE_SS|IN_IGNITION|SW_COOLANT|SW_DROOP|"
    r"TRIP_SENSE|RLY_MAIN|RLY_BUZZER|EGR_EN|CAM_EDGE|CRANK_EDGE|"
    r"INJ_HS_[AB](_BAT)?|can/CAN[12]_STB|mcu/WDT_FAULT|mcu/~\{RESET\}|"
    r"metering_egr/EGR_SD|injector/U[AB][12]_HIN)$|^Net-\(U302-")
LOGIC5_RE = re.compile(
    r"^/(BARO|BOOST_P|BOOST_T|COOLANT_T|EGR_POS|OIL_P|RAIL_P)$|"
    r"^Net-\(U60[1-6]-(OUT|VOUT)\)$")

# Bootstrap domains: every net in one domain rides on the first, and a
# part with both ends in the domain sees only the gate-drive swing.
DOMAINS = [
    ["/INJ_A_03", "/injector/UA1_VB", "/injector/UA2_VB",
     "/injector/HSA_BOOST_GATE", "/injector/HSA_BAT_GATE"],
    ["/INJ_B_05", "/injector/UB1_VB", "/injector/UB2_VB",
     "/injector/HSB_BOOST_GATE", "/injector/HSB_BAT_GATE"],
    ["/EGR_HIGH_59", "/metering_egr/EGR_A_VB", "/metering_egr/EGR_AH_G"],
    ["/EGR_LOW_81", "/metering_egr/EGR_B_VB", "/metering_egr/EGR_BH_G"],
    ["/rails/SW", "/rails/BST"],
]

# Parts where "the worse of its two nets" over-states what is ACROSS it:
# series strings between two biased nodes, and parts that carry only AC.
# Keyed by the net pair, not the ref -- refs move when parts are added.
# (v_cont, v_peak, why)
PAIR_V = {
    ("/injector/BIAS_12V_MID", "/injector/BOOST_100V"):
        (45.5, 45.5, "upper half of the 47k/47k zener bias string"),
    ("/injector/BASE_12V", "/injector/BIAS_12V_MID"):
        (45.5, 45.5, "lower half of the 47k/47k zener bias string"),
    ("/power_input/VBAT_CLAMPED", "/power_input/VBAT_EMI1"):
        (0.2, 1.0, "ferrite damper Rf, across Lf: filter AC only"),
    ("/12V_GATE", "/injector/Q1E_12V"):
        (0.28, 0.65, "56 ohm limit sense: 5 mA, one Vbe at the limit"),
    ("/CAN1_H", "/can/CAN1_SPLIT"): (1.0, 40.0, "half the 2 V dominant"),
    ("/CAN1_L", "/can/CAN1_SPLIT"): (1.0, 40.0, "half the 2 V dominant"),
    ("/CAN2_H", "/can/CAN2_SPLIT"): (1.0, 40.0, "half the 2 V dominant"),
    ("/CAN2_L", "/can/CAN2_SPLIT"): (1.0, 40.0, "half the 2 V dominant"),
}

# Sense shunts are a different product family (metal element, milliohm);
# they carry their own package in the value string or here.
SHUNT_FP = {
    "5mOhm 2W 1%": "Resistor_SMD:R_2512_6332Metric",
    "20mOhm 1W 1%": "Resistor_SMD:R_2512_6332Metric",
    "50mOhm 1%": "Resistor_SMD:R_1206_3216Metric",
    "82mOhm 1%": "Resistor_SMD:R_1206_3216Metric",
}

R_FP = {s: f"Resistor_SMD:R_{s}_{m}Metric" for s, m in [
    ("0402", "1005"), ("0603", "1608"), ("0805", "2012"),
    ("1206", "3216"), ("1210", "3225"), ("2010", "5025"),
    ("2512", "6332")]}
C_FP = {s: f"Capacitor_SMD:C_{s}_{m}Metric" for s, m in [
    ("0402", "1005"), ("0603", "1608"), ("0805", "2012"),
    ("1206", "3216"), ("1210", "3225"), ("1812", "4532")]}

# What exists: KEMET C1023 X7R AUTO (AEC-Q200), "Table 1 -- Capacitance
# Range/Selection Waterfall", retrieved 22 Sep 2026 and parsed by x
# coordinate (tools/parse_kemet_waterfall.py -- the text layout
# compresses the data columns and mis-assigns them). capacitance ->
# [(case, rated V)]. A (value, rating) pair absent here stops the script.
KEMET = json.load(open(os.path.join(HW, "lib", "kemet_x7r_auto.json")))
C_CASES = ["0603", "0805", "1206", "1210", "1812"]   # smallest first
C_FLOOR = 25.0          # <=1 uF: never below 25 V, for DC-bias headroom
SPECIAL_C = {           # not MLCC -- chosen separately
    "150uF": "polymer, PDN-BULK ESR band -- chosen separately",
    "47uF 150V": "aluminium electrolytic -- chosen separately",
}


CLAMP_NODE = (3.1, 4.4)      # BAV199-Q node: signal max / one diode up
BUFFER_BASE = (1.0, 1.1)     # discrete-input NPN base: one Vbe, or -1 V


def netv(n):
    if n in NET_V:
        return NET_V[n]
    if n.endswith("_CL"):
        return CLAMP_NODE
    if n.startswith("/discrete_io/") and n.endswith("_B"):
        return BUFFER_BASE
    if LOGIC3_RE.search(n):
        return LOGIC3
    if LOGIC5_RE.search(n):
        return LOGIC5
    raise SystemExit(f"no voltage for net {n!r} -- add it to NET_V")


def across(a, b):
    key = tuple(sorted((a, b)))
    if key in PAIR_V:
        return PAIR_V[key][:2]
    for d in DOMAINS:
        if a in d and b in d:
            return GATE12
    (ca, pa), (cb, pb) = netv(a), netv(b)
    return max(ca, cb), max(pa, pb)


def parse_value(v):
    """'2R2' 2.2, '120R' 120, '4.7k' 4700, '82mOhm' 0.082, '100nF' 1e-7,
    '4.7uF/100V' 4.7e-6 -- the leading quantity only."""
    m = re.match(r"^(\d+)R(\d*)\b", v)
    if m:
        return float(f"{m.group(1)}.{m.group(2) or 0}")
    m = re.match(r"^([\d.]+)\s*([pnumkM]?)", v)
    if not m:
        raise SystemExit(f"cannot read value {v!r}")
    mul = {"p": 1e-12, "n": 1e-9, "u": 1e-6, "m": 1e-3, "k": 1e3,
           "M": 1e6, "": 1.0}[m.group(2)]
    return float(m.group(1)) * mul


def netlist():
    fd, path = tempfile.mkstemp(suffix=".net")
    os.close(fd)
    subprocess.run(["kicad-cli", "sch", "export", "netlist", "-o", path,
                    os.path.join(HW, "ecu25kva.kicad_sch")], check=True,
                   capture_output=True)
    text = open(path).read()
    os.unlink(path)
    return text


def main():
    text = netlist()
    comps = dict(re.findall(r'\(comp \(ref "([^"]+)"\)\s*\(value "([^"]*)"',
                            text))
    netsof = collections.defaultdict(list)
    for blk in text.split("(net (code")[1:]:
        name = re.search(r'\(name "([^"]+)"', blk).group(1)
        for ref, _pin in re.findall(
                r'\(ref "([^"]+)"\)\s*\(pin "([^"]+)"', blk):
            netsof[ref].append(name)

    out, unresolved = {}, []
    for ref, val in sorted(comps.items()):
        kind = ref[0]
        if kind not in "RC" or not re.match(r"^[RC]\d", ref):
            continue
        if kind == "C" and re.match(r"^C\d", ref) and "uF 150V" in val:
            continue                     # electrolytic, chosen separately
        nets = netsof[ref]
        if len(nets) != 2:
            continue
        vc, vp = across(*nets)
        if kind == "R":
            if val in SHUNT_FP:
                out[ref] = (SHUNT_FP[val], f"shunt: {val}")
                continue
            m = re.search(r"\b(2512|2010|1210|1206)\b", val)
            if m:
                out[ref] = (R_FP[m.group(1)], f"size stated in value")
                continue
            r = parse_value(val)
            if "1W" in val:
                out[ref] = (R_FP["2512"], "1 W stated in value")
                continue
            if r == 0.0:
                out[ref] = (R_FP[R_MIN_SIZE], "0R jumper")
                continue
            p = vc * vc / r
            sizes = [x[0] for x in R_SIZES]
            for size, p70, umax in R_SIZES[sizes.index(R_MIN_SIZE):]:
                if p <= p70 * DERATE and vp * V_MARGIN <= umax:
                    out[ref] = (R_FP[size],
                                f"{vp:.1f} V peak, {p*1e3:.1f} mW cont; "
                                f"{size} = {umax:.0f} V, "
                                f"{p70*DERATE*1e3:.0f} mW at {T_BOARD:.0f} C")
                    break
            else:
                unresolved.append((ref, val, nets, vc, vp, p))
        else:
            if val in SPECIAL_C:
                continue
            c = parse_value(val)
            need = max(vp, 1.5 * vc)
            if c <= 1.01e-6:
                need = max(need, C_FLOOR)
            m = re.search(r"(\d+)V", val)
            if m:
                need = max(need, float(m.group(1)))
            have = KEMET.get(f"{c:.3e}", [])
            pick = None
            for case in C_CASES:
                rs = sorted(v for cs, v in have if cs == case and v >= need)
                if rs:
                    pick = (case, rs[0])
                    break
            if pick:
                out[ref] = (C_FP[pick[0]],
                            f"{vp:.1f} V peak, needs >= {need:.0f} V; "
                            f"KEMET X7R AUTO {pick[0]} {pick[1]:g} V")
            else:
                unresolved.append((ref, val, nets, vc, vp, need))

    if "--report" in sys.argv or unresolved:
        need = collections.Counter()
        for u in unresolved:
            if u[0][0] == "C":
                need[(u[1], u[5])] += 1
            else:
                print("  R unresolved:", u)
        for (v, r), n in sorted(need.items(), key=lambda x: (x[0][1], x[0][0])):
            print(f"  C needs a package: {v} at >= {r:.0f} V  x{n}")
    with open(OUT, "w") as f:
        json.dump({k: {"footprint": v[0], "why": v[1],
                       "value": comps[k]} for k, v in out.items()},
                  f, indent=1, sort_keys=True)
    print(f"{OUT}: {len(out)} parts packaged, {len(unresolved)} unresolved")
    return 1 if unresolved else 0


if __name__ == "__main__":
    sys.exit(main())

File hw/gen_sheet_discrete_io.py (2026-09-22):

#!/usr/bin/env python3
"""discrete_io sheet: switch inputs, the supervised trip loop, relay drivers.

Six input channels and two outputs. Three blocks back it:
discrete_input.cir, trip_module_sense.cir, relay_driver.cir.

ONE PIN ASSIGNMENT IS CORRECTED HERE, and it is not a preference.
docs/pinmap.md assigns the trip-module sense to PTD6 as a "GPIO input".
trip_module_sense.cir designs a THREE-STATE supervised loop and checks
the three bands with real margins:

    healthy (contact closed)   2.863 - 2.954 V
    tripped (Rt in circuit)    0.310 - 2.068 V
    wire fault                 0.000 V

A GPIO reads two states. It can separate healthy from not-healthy and
nothing else -- which discards exactly the distinction the bleed resistor
exists to create, and a supervised loop that cannot report a cut wire is
an unsupervised loop with extra parts. The channel moves to PTB0
(ADC0_SE4), which is free, bonded out on the 144-LQFP, and Hi-Z with no
pull at reset. PTD6 returns to the spare pool.
"""
import os
import sys

sys.path.insert(0, os.path.dirname(os.path.abspath(__file__)))
import schlib
from schlib import Sheet, Rail, pin_xy, PINS
import json

HW = os.path.dirname(os.path.abspath(__file__))
OUT = os.path.join(HW, "discrete_io.kicad_sch")
GND_DROP = 7.62
QP = PINS["Device:Q_NMOS_GSD"]
ICPINS = json.load(open(os.path.join(HW, "lib", "ic_pins.json")))


def ic_pin(part, num, x, y):
    dx, dy = ICPINS[part][str(num)]
    return pin_xy(dx, dy, x, y, 0)


def gnd_below(sh, x, y):
    sh.wire(x, y, x, y + GND_DROP)
    sh.gnd(x, y + GND_DROP)


def vshunt(sh, libid, prefix, x, y, value, fields, rail, rot=0):
    """A part from a rail down to ground."""
    sh.place(libid, prefix, x, y, value, rot=rot, fields=fields)
    a = pin_xy(*PINS[libid]["1"], x, y, rot)
    b = pin_xy(*PINS[libid]["2"], x, y, rot)
    t, bo = (a, b) if a[1] < b[1] else (b, a)
    rx, ry = rail.to(t[0], tap=True)
    sh.wire(rx, ry, t[0], t[1])
    gnd_below(sh, bo[0], bo[1])


def clamped_input(sh, x0, y, in_net, out_net, label, pullup=None):
    """discrete_input.cir's front-end: 47k series, 68k to ground, 220 nF,
    and a 3.0 V zener. The zener does the clamping and the 47k sets what
    it has to sink -- (40 - 3) / 47k = 787 uA at the top of the input
    range, which is why the series element is not a token value."""
    sh.hlabel(in_net, x0, y, shape="input")
    chain = Rail(sh, y)
    chain.to(x0)

    # Optional pull-up, for the two channels whose switch is a contact to
    # ground rather than a feed. Placed BEFORE the 47k so a battery short
    # on the harness still meets the clamp chain rather than the pull-up.
    if pullup:
        sh.place("Device:R", "R", x0 + 16.0, y - 18.0, pullup,
                 fields={"Source": "pull-up for a switch-to-ground contact "
                                   "(pinmap sec.1.4)",
                         "Note": "Open contact leaves the divider at "
                                 "5 * 115/125 * 68/115 = 2.72 V, under the "
                                 "3.0 V zener knee, so it reads high "
                                 "without the clamp conducting. Closed "
                                 "contact pulls it to 0 V."})
        a = pin_xy(*PINS["Device:R"]["1"], x0 + 16.0, y - 18.0, 0)
        b = pin_xy(*PINS["Device:R"]["2"], x0 + 16.0, y - 18.0, 0)
        t, bo = (a, b) if a[1] < b[1] else (b, a)
        rx, ry = chain.to(x0 + 16.0, tap=True)
        sh.wire(rx, ry, bo[0], bo[1])
        sh.wire(t[0], t[1], t[0], t[1] - 6.35)
        sh.hlabel("5V_MAIN", t[0], t[1] - 6.35, shape="input",
                  rot=90)

    sx = x0 + 34.0
    sh.place("Device:R", "R", sx, y, "47k", rot=90,
             fields={"Source": "discrete_input.cir R5",
                     "Note": "Sets the zener's worst-case sink current: "
                             "(40 - 3) / 47k = 787 uA at the top of the "
                             "6-40 V input range"})
    ra = pin_xy(*PINS["Device:R"]["1"], sx, y, 90)
    rb = pin_xy(*PINS["Device:R"]["2"], sx, y, 90)
    r_in, r_out = (ra, rb) if ra[0] < rb[0] else (rb, ra)
    rx, ry = chain.to(r_in[0])
    node = Rail(sh, y)
    node.to(r_out[0])

    vshunt(sh, "Device:R", "R", x0 + 54.0, y + 18.0, "68k",
           {"Source": "discrete_input.cir R6",
            "Note": "With the 47k above, a 115k divider -- but the zener "
                    "is what sets the clamped level, not this ratio"}, node)
    vshunt(sh, "Device:C", "C", x0 + 70.0, y + 18.0, "220nF",
           {"Source": "discrete_input.cir C1 -- debounce and EMI",
            "Note": "68k * 220 nF = 15 ms, long against contact bounce and "
                    "short against anything the engine does"}, node)
    # Zener: cathode to the signal, anode to ground.
    vshunt(sh, "Device:D_Zener", "D", x0 + 86.0, y + 18.0, "3.0V",
           {"Source": "discrete_input.cir D1",
            "Note": "Clamps the MCU pin at 3.0 V across the whole 6-40 V "
                    "input range. Cathode to the signal."}, node, rot=270)

    node.to(x0 + 108.0)
    sh.hlabel(out_net, x0 + 108.0, y, shape="output")
    sh.text(label, x0, y - 9.0, size=1.6)
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

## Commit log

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2026-09-13 Add simulation harness and first two verified circuit blocks
    Drives the libngspice shared library that KiCad already ships, via
    ctypes, so circuits can be simulated headless and checked against
    claims rather than asserted to work. PySpice's own wrapper was
    unusable here -- it treats ngspice's stderr chatter as fatal.
    Each block carries checks that are claims about the circuit, so a red
    line means the design is wrong, not the simulator. Verified the harness
    against analytic theory first: an RC corner lands at 1584.9 Hz against
    1591.5 Hz predicted, with exactly -36 dB at 100 kHz confirming
    single-pole rolloff.
    Two real errors caught on the first run.
    Battery sense fed 4.69 V into a 3.3 V AD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
    [run_sim.py]
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2026-09-13 Add four more verified circuit blocks
    Six blocks now simulate and pass: battery sense, discrete input,
    ratiometric sensor front-end, ISO 7637-2 transient clamp, injector
    boost comparison, relay driver.
    The transient clamp turned up a real finding. Under ISO 7637-2 pulse
    2a at Level IV the SMBJ33CA clamps at ~50 V, not the 'under 42 V' the
    earlier artifacts asked for. That target was never derivable from a
    datasheet -- the real part is specified at 53.3 V clamping at rated
    pulse current -- so 50 V is the part working correctly. It sits inside
    the LM5164's 100 V rating with 2x margin and leaves 60 V-class parts
    viable, so the 42 V figure should be dropped rather than chased with a
    lower-volta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
    [run_sim.py]
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2026-09-13 Add schematic drawings for all six circuit blocks
    Drawn with schemdraw from sim/draw_schematics.py, which mirrors the
    netlists in sim/blocks/ so the picture and the simulated circuit cannot
    drift apart. Exported as SVG and PNG, and inlined into the handbook.
    SVGs are post-processed to use currentColor rather than black, so the
    drawings take the surrounding text colour and stay legible in both light
    and dark themes. PNGs stay fixed dark-on-white for pasting into slides.
    Two layout notes worth keeping: schemdraw puts the NFet gate on the
    right, so the relay driver's flyback diode sits to the left of the coil
    to stop the gate lead crossing back over it; and loc= on a rotated
    element lands unp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
    [draw_schematics.py]
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2026-09-14 Build the power chain: five new simulated blocks
    Takes spec section 6 from a seven-row table with one built stage to six.
    New blocks: emi_filter, reverse_battery, buck_preregulator, sensor_rail,
    mcu_pdn. 11/11 blocks pass.
    Three of the five failed their first run for real reasons, and each fix is
    a design decision rather than a tolerance change:
    buck_preregulator sat at 0.27 V instead of 5 V. Voltage-controlled switches
    have no body diode, so during the 20 ns dead time the inductor current had
    no path at all and was reset through the switch model's 1 GOhm off-state
    every cycle. Added body diodes, and started both cases in steady state --
    the output filter rings at 4 kHz with a Q near 6, so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
    [run_sim.py]
2026-09-14 Build the remaining subsystems: 17 circuit blocks, all passing
    Six new blocks take the design from the power chain alone to every
    subsystem that is not blocked on the engine visit: vr_conditioner,
    sensor_differential, boost_converter, ntc_frontend, metering_unit_pwm,
    can_termination.
    Findings worth recording, because each changed a design decision:
    vr_conditioner. A fixed 5 V comparator threshold, perfectly sensible
    against a 20 V running-speed signal, produces all 30 teeth at 1500 rpm and
    zero at cranking, where the VR sensor makes 2 V. That is the worst failure
    shape available -- it passes on the bench and the engine never starts.
    Zero-crossing with hysteresis works at both.
    ntc_fronten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
    [build_circuit_page.py, draw_schematics.py, run_sim.py]
2026-09-14 Resolve spec section 4 after SME review; close two review findings
    Two SME reviews of the work so far found, among other things, that spec
    section 4 and the simulated analog front-end described incompatible
    circuits. This resolves that, which was the blocker on any further analog
    work.
    Section 4 previously specified "1 kOhm series, 100 nF shunt, ADC ref tracks
    5V_SENSOR". Both halves were wrong, and for the same reason the 75k/10k
    battery divider was wrong -- they were written for a 5 V part. The
    S32K148's VREFH may not exceed its 3.3 V analog supply, so no reference can
    track a 5 V rail; and 1 kOhm in series scales nothing, so a 4.5 V sensor
    output arrives at a 3.3 V pin.
    The buildable an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
    [build_circuit_page.py, run_sim.py]
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2026-09-18 Bring every live document to current status
    Sweep after the 18 September field evidence. The rule applied: memos are dated
    records and keep supersession banners rather than being rewritten; live
    documents -- the spec, the handbook, the README, the PDF cover, the generated
    circuit page -- are brought fully current.
    Handbook. The machine section now names 3GK550ETA 4SR1 with its application
    code, type approval and the DSE4522 controller, and its "On the name GK550" note
    is rewritten to say plainly that our inference was wrong and the original
    description was right. That note previously told readers GK550 "will find
    nothing" when ordering parts, which was actively misleading advice.
    Handbook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
    [build_circuit_page.py]
2026-09-18 Simulate ISO 7637-2 pulse 5b; the input TVS fails it
    Adds the load_dump block, the first of the two CRITICAL gaps the circuit
    review found. Spec section 6 requires ISO 7637-2 including load dump 5b;
    only pulse 2a had ever been modelled.
    Pulse 2a is 50 us and is a peak-voltage problem. Pulse 5b runs to 400 ms,
    which makes it an energy problem, and the SMBJ33CA-class part chosen
    against 2a absorbs 46.4 J at 116 W average -- roughly 100x both its
    single-pulse energy rating and its continuous dissipation rating.
    The block FAILS, deliberately. 17/18 blocks pass.
    The verdict hinges on one inequality. Re-running at Us* = 35 V, the
    figure usually quoted for a 12 V suppressed dump, the TVS never r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
    [build_circuit_page.py, draw_schematics.py, run_sim.py]
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2026-09-18 Make the schematics agree with each other and with the spec
    Four drawings of the same input stage told three different stories about
    stage order. Spec section 4 states it authoritatively -- EMI filter,
    fuse, TVS, reverse-battery FET -- and the schematics now follow it. This
    is the ambiguity that let a 40 V FET be specified for a node the
    neighbouring block had already measured at 50 V: when no drawing agrees
    on what is upstream, nobody owns the question.
    The duplicate ferrite that transient_clamp and load_dump were drawing
    turned out to be the EMI filter's own part, redrawn a stage downstream of
    where it lives.
    Parts that are physically real but not modelled in the netlist are now
    dashed,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
    [build_circuit_page.py, draw_schematics.py]
2026-09-18 Tolerance notes and regression-pin labelling, 11 of 19 blocks
    Partial. The pass covered battery_sense, buck_preregulator, discrete_input,
    emi_filter, injector_boost, injector_turnoff, relay_driver,
    reverse_battery, sensor_rail, sensor_ratiometric and transient_clamp
    before the session cap stopped it. Eight blocks remain: boost_converter,
    can_termination, mcu_pdn, metering_unit_pwm, ntc_frontend,
    sensor_differential, vr_conditioner, and load_dump's own second parameter.
    Two things are being fixed here. Every netlist stated its component values
    as fixed constants, so every PASS was a nominal-value result with no
    statement of what it depended on. And checks whose expected value was
    simply the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
    [run_sim.py]
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2026-09-18 Finish the tolerance pass; fix the last two schematic drift cases
    Tolerance notes now cover all 19 blocks. No component value changed in
    any netlist -- the work is a statement of what each block's verdict
    depends on, which none of them made before.
    Three blocks fail their corner, and they fail differently:
    mcu_pdn genuinely inadequate. A 26% nominal margin evaporates
    when the LDO's output inductance is taken at 0.35 uH
    instead of the 0.15 uH the netlist assumed, and no
    part is chosen that would settle which it is. The fix
    is demonstrated (double the bulk capacitance, the
    same lever thi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
    [build_circuit_page.py, draw_schematics.py, run_sim.py]
2026-09-18 Raise the MCU bulk capacitance to 150 uF, and stop the verdict depending on an unmeasured number
    The tolerance pass judged this the one block genuinely inadequate: at
    47 uF it cleared its 100 mOhm target only at the nominal value of the
    LDO's output inductance, a parameter no chosen part pins down. 26% margin
    against 74.2 mOhm nominal, 145.9 mOhm at a plausible restatement. A
    margin that evaporates when an unmeasured number is restated is not a
    margin, and the target is the derived kind -- 50 mV ripple over a 0.5 A
    step -- so it could not be argued away either.
    Swept both parameters together rather than taking the first value that
    passed. 100 uF clears 0.35 uH and then fails at 0.5 uH, whic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
    [build_circuit_page.py, draw_schematics.py, run_sim.py]
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2026-09-18 Simulate the supervisor and fail-safe gate path; the 10k pulldown fails
    Builds memo 11's recommendation: a windowed supervisor watching 3V3_MCU,
    its reset driving a kill transistor at each driver gate, in parallel with
    a standing gate-source pulldown.
    Claim 4 -- the memo's central argument -- holds, and holds well. Across
    six brownout ramps from 293 us to 1000 ms, with an adversarial driver
    actively fighting the gate the whole time, the kill path always finishes
    before 3V3_MCU crosses the S32K148's 2.97 V correctness floor. Tightest
    margin is 18 us at the fastest ramp and grows to 61 ms at the slowest, so
    a slow sag gives the supervisor more time rather than less. The safe
    state does not de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
    [build_circuit_page.py, draw_schematics.py, run_sim.py]
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2026-09-18 Close out the pulldown error: sweep the free parameter, find what it costs
    The correction said 10 kOhm was wrong and gave a formula. It did not say
    what value to fit, and the block still hard-coded 10 kOhm in every branch
    -- including claim 2, which is the check that bounds the pulldown from
    below. So the block was testing a rejected value and the requirement had
    no number behind it.
    Claim 6 sweeps the pulldown instead of the coupling capacitance, at
    Crss = 500 pF, the pessimistic end of the class range:
    220 ohm -> 0.308 V 1000 ohm -> 1.401 V
    470 ohm -> 0.658 V 2200 ohm -> 3.077 V
    4700 ohm -> 6.267 V
    470 ohm, twenty times smaller than the figure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
    [run_sim.py]
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2026-09-19 Fix two review findings in supervisor, and stop evidence rows hiding drift
    An independent review re-ran claim 3's table and found the 20 pF row
    stated 0.235 V against an actual 0.465 V, exactly 2x out, with its naive
    I*R column wrong the same way -- 56 uA through 10 kOhm is 0.56 V, not
    0.28. The other five rows reproduce exactly. The comment above the table
    claimed the figures were read off the simulation rather than hand-typed.
    That was not true of that row.
    This happened inside the file written to fix memo 11's 1000x hand
    arithmetic, in the very table doing the fixing.
    It was uncatchable because I had converted those rows to ok=True when
    relabelling them as evidence rather than gates. Th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
    [run_sim.py]
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2026-09-19 Add the EGR H-bridge and the trip-module sense input
    Two of the four circuits the status page listed as having no netlist at
    all. 22 blocks now, 21 passing.
    egr_hbridge drives a positional actuator on pins 59/81 with feedback on
    37, which is why it is a bridge and not the low-side switch everything
    else here uses. Fail-safe on reset is coast, not brake, leaving the
    return spring to close the valve. Position feedback is not rebuilt --
    sensor_ratiometric.cir already covers that front end and is cited rather
    than duplicated. Its verdict hinges on an armature resistance nobody has
    chosen: stall current swings 2.6-6.4 A across a plausible range, which
    straddles a class-typical driver's rating ei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
    [build_circuit_page.py, draw_schematics.py, run_sim.py]
2026-09-19 Add the cam front-end that spec section 4 would have destroyed a pin with
    Spec section 4 specified pin 46's cam input as a pull-up to the 5 V
    sensor rail feeding a timer capture, on a 3.3 V part. That is above the
    S32K148's absolute maximum. It survived because nothing simulated it --
    there is a vr_conditioner block for the crank sensor and no cam
    equivalent, so the one mechanism here that catches this class of error
    never looked.
    The block divides the 5 V swing into the 3.3 V domain and checks the
    result across the rail's own range rather than at one point: 3.072 V at
    nominal, 3.147 V at 5.25 V high line, and 2.769 V at the 4.5 V floor
    sensor_rail.cir already established for a fault condit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
    [build_circuit_page.py, draw_schematics.py, run_sim.py]
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2026-09-19 Model the TVS as the bidirectional part it actually is
    Both clamp blocks used a single diode. The real SMBJ33CA is
    bidirectional -- the CA suffix says so -- and a single diode conducts
    forward at 0.7 V in reverse polarity, so the model would have answered
    any reverse-polarity or negative-pulse question confidently and wrongly
    rather than failing visibly. That is what blocked simulating ISO 7637-2's
    negative pulses, which spec section 6 requires and nothing has modelled.
    Now two anti-series junctions, split so the whole device still matches
    the datasheet it stands for rather than each junction doing: one
    avalanches at 36.0 V while the other is forward-biased, summing to the
    36.7 V the single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
    [run_sim.py]
2026-09-19 Simulate ISO 7637-2's negative pulses; the buck has no negative protection
    Spec section 6 requires ISO 7637-2 and only the positive pulses had ever
    been modelled. This became answerable this morning, when the TVS stopped
    being a single diode.
    The finding is a missing component, not a mis-sized one. The LM5164's VIN
    pin is rated -0.3 V to 100 V -- the negative limit is not a mirror of the
    positive one, and nothing in this design was ever sized against it. With
    the reverse-battery FET assumed still conducting, the buck's VIN sees
    -40.7 V on pulse 1 and -27.8 V on pulse 3a: 135x and 93x past that
    rating. The TVS clamps correctly; -38 V is a perfectly good clamp that is
    still two orders of magn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
    [build_circuit_page.py, draw_schematics.py, run_sim.py]
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2026-09-19 Enforce the temperature corners as checks; 17 of 24 blocks pass
    The corner pass found six blocks failing cold or hot and recorded every
    one in prose, inside RESULT NOTE comments, while the suite went on
    reporting 22 of 24 passing. This project has found four wrong numbers in
    prose this week and none in a check. That is the wrong place for them.
    The pass count is now 17 of 24. That is the point of the commit, not a
    regression.
    Five blocks now fail a corner they always failed, and the distinction
    between them matters:
    sensor_rail fault current 4.148 A against a real 3.0 A polyfuse
    trip ceiling, at the stacked cold-and-tolerance
    corner
    mcu_pd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
    [run_sim.py]
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2026-09-19 The EGR bridge shorts both legs at 270 A, and the file said it could not
    A review falsified egr_hbridge.cir's own shoot-through claim against its
    own wiring. The file argued that because each input line drives a
    DIAGONAL pair, no IN1/IN2 combination could connect a leg's high and low
    side, and that the worst a stuck-high pair could do was a low-side brake.
    IN1 commands S1 (leg A high) and S4 (leg B low). IN2 commands S3 (leg B
    high) and S2 (leg A low). Assert both and all four switches are on:
    S1+S2 short leg A from rail to ground and S3+S4 short leg B, at the same
    time. The reasoning failed by checking each input line on its own and
    never asking what the two do together.
    Simulated rather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
    [run_sim.py]
2026-09-20 Resolve input protection: SMCJ43CA plus a negative clamp diode
    Two coupled part decisions, both simulated rather than asserted.
    The TVS standoff had to clear the 40 V clamped load dump so the part
    stops conducting during a normal event -- which is what load_dump's
    failure was actually saying rather than that the part was too small.
    43 V is the smallest standard bin above 40 V, and smallest matters
    because clamping voltage rises with the bin and everything downstream
    sees it. load_dump now draws 0.000 A and absorbs 0.000 J. It passes.
    The package change was forced by simulation, not chosen. At the 600 W
    SMBJ size, pulse 2a clamped at 88.6 V against the buck's 100 V absolute
    maximum -- 11 pe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
    [run_sim.py]
2026-09-20 Resolve the EGR shoot-through: decoded DIR/PWM inputs
    The fault state was a property of wiring two logic lines straight to two
    diagonal switch pairs. An integrated driver does not expose it: DIR
    selects the diagonal, PWM gates the bridge, and no input combination can
    turn on both switches of one leg.
    Demonstrated rather than asserted. The same bridge under decode, with
    BOTH inputs asserted -- the combination that shorts the naive
    arrangement -- draws 4.35 A, which is the motor's own stall current.
    270 A against 4.35 A. The fault state stops existing rather than
    becoming less likely.
    The naive wiring stays in the netlist as evidence of why the requirement
    exists, pinned with a tolerance so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
    [run_sim.py]
2026-09-20 Specify the CAN termination resistors, and stop pinning a nominal as a requirement
    Two blocks were failing at temperature corners for different reasons,
    and only one of them was a design problem.
    can_termination: the 200 ppm/C thick-film corner puts differential
    impedance at 123.95 ohm against J1939's own 120 ohm. That is a real
    inadequacy, so it is answered by specifying the part rather than by
    widening the check -- Rah/Ral become 60.0 ohm thin-film, 0.1% initial,
    50 ppm/C. Network "f" runs both mechanisms stacked the adverse way
    (60 * 1.00825 * 1.001) and lands at 121.10 ohm, inside the window with
    0.90 ohm to spare. The thick-film corner stays as pinned evidence of
    why the requirement ex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
    [run_sim.py]
2026-09-20 Specify the sensor-rail PTC and the PDN bulk capacitor
    Both blocks were failing at corners that are real requirements, so
    both are answered by specifying a part rather than by widening a
    check. Each keeps its failing corner as pinned evidence of why the
    requirement exists.
    sensor_rail: at -40 C stacked with -30% part spread, a 2.0 ohm PTC
    lets 4.15 A through a shorted harness against a 3.0 A ceiling -- the
    ceiling being that the polyfuse has to clear the fault, not the 5 V
    regulator's own current limit. Solving the fault loop against that
    ceiling gives R25 > 2.78 ohm, so the specified part is 3.0 ohm. At
    the same stacked corner it draws 2.88 A, 0.12 A under.
    A larger series resistance coul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
    [run_sim.py]
2026-09-20 The metering unit needs current control, not duty control
    This is the one failing corner that no part specification could fix.
    The coil is copper, copper moves 0.39%/C, and over the -40/+125 C
    range the design has to survive its resistance goes 7.39 -> 13.82 ohm.
    At a fixed 50% duty the mean current follows it: 0.862 A cold against
    0.462 A hot, +27% and -32% around a 0.675 A setpoint. There is no
    better resistor to buy.
    Branch 4 is the answer the block was missing -- a hysteretic current
    regulator, the simplest form of closed-loop control and the one that
    needs no compensation network. It holds 0.679 / 0.679 / 0.683 A at
    -40 / 25 / +125 C, inside the same +/-0.09 A band the open-loop checks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
    [run_sim.py]
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2026-09-20 Create the KiCad project: ten hierarchical sheets, generated not drawn
    Phase 2 starts here. hw/gen_project.py writes the root sheet and any
    child sheet that does not exist yet; a child sheet that already has
    content is never touched, so work done in Eeschema is safe against a
    re-run.
    Generated rather than hand-drawn because three lists have to stay in
    step -- the sheets, the simulation blocks in sim/blocks/, and the
    requirement tags in docs/bom_requirements.md -- and a root sheet edited
    by hand drifts from them silently. Each sheet symbol carries its
    SimBlocks and BomTags as hidden properties, so the mapping travels with
    the schematic instead of living in a document beside it.
    Sheet order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
    [can.kicad_sch, connector.kicad_sch, discrete_io.kicad_sch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]
2026-09-20 Recover the S32K148 pin table and generate its symbol from it
    docs/pinmap.md assigned 37 PTxx signals by reading NXP's
    S32K148_IO_Signal_Description_Input_Multiplexing.xlsx -- which is not a
    download but one of eleven workbooks embedded as file attachments inside
    the S32K1xx Reference Manual PDF, and the only place the per-package pin
    numbers exist. The datasheet says so itself (Rev. 15 sec.10.1), and the
    Reference Manual's Chapter 4 defers to the attachments rather than
    inlining them.
    That file was extracted once and not kept. So pinmap.md cited a source
    the repo no longer held, and the symbol could not be built from it. The
    workbook is now in refs/, along with the URL and checksums of bot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
    [S32K148_IO_Signal_Description_Input_Multiplexing.xlsx, s32k148-144lqfp-altfn.csv, s32k148-144lqfp-pins.csv]
2026-09-20 Draw the power_input sheet, and a generator for the nine after it
    hw/schlib.py is the reusable piece: a minimal KiCad 7 schematic writer
    that places symbols, wires them, labels nets and exposes hierarchical
    pins. Symbol definitions are copied out of the installed libraries into
    each sheet's own (lib_symbols) block, which is what KiCad expects.
    Generated rather than hand-drawn because almost no component value on
    these sheets is a free choice -- nearly every one traces to a check in
    sim/blocks/ or a tag in docs/bom_requirements.md. A hand-drawn sheet
    holds those as text nobody re-derives, and they drift the moment a
    simulation moves, which has already happened three times with the
    reverse-ba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
    [power_input.kicad_sch]
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2026-09-20 Draw the mcu sheet, and choose the supervisor part
    The S32K148 with all 144 pins wired, the TPS3850G33 watching its rail,
    the inverting stage that turns the supervisor's active-low RESET into an
    active-high GATE_KILL for the driver sheets, mcu_pdn.cir's decoupling
    network, and the debug header. A2 rather than A3: six 25-pin units plus
    a supervisor, a header and eleven decoupling parts do not fit A3 without
    stacking, and a schematic whose parts overlap is one nobody reads.
    THE SUPERVISOR IS NOW A PART, NOT A CLASS. Memo 11 had TPS3850 CONFIRMED
    on its electricals but recommended it as "TPS3850-class", and the pinout
    was never captured. Both are settled here from the retrieved datasheet
    (TI S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
    [mcu.kicad_sch, power_input.kicad_sch]
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

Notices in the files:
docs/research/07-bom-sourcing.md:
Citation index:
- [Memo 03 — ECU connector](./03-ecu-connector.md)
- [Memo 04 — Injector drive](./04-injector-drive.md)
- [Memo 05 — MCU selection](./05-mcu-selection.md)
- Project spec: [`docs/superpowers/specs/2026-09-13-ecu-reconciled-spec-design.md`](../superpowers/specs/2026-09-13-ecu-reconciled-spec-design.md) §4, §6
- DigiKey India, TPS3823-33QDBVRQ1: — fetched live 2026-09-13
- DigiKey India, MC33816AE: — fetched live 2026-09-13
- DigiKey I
